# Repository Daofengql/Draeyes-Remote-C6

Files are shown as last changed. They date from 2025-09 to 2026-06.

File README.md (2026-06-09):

# Draeyes Remote C6 完整版遥控器

Draeyes Remote C6 是 Draeyes 兽装可动眼系列的完整版手持遥控器固件与硬件资料仓库。该版本面向 ESP32-C6 主控硬件，使用摇杆、肩键、同步拨动开关和可选 VEML7700 环境光传感器，通过纯 ESP-NOW 向接收端发送低延迟控制数据。

完整版遥控器适合正式使用场景：支持手动视线控制、全自动仿生眼动、自动眨眼、左右眼皮手动控制、摇杆锁定、摇杆零点校准、接收端配对，以及基于环境光的亮度或瞳孔响应控制。

早期设计中预留过 WiFi AP 和 MQTT 辅助功能，当前公开版本已经移除这些未使用模块，以减少固件体积、依赖库和运行时内存占用。

## 硬件配置

| 项目 | 说明 |
| --- | --- |
| 主控 | ESP32-C6 |
| 无线协议 | ESP-NOW |
| 主要输入 | 二轴模拟摇杆 |
| 按键 | R1、R2、LB、RB |
| 拨动开关 | BK，左右眼皮同步 |
| 光照传感器 | VEML7700，I2C |
| 参数保存 | EEPROM 模拟，用于保存摇杆零点和亮度补偿 |

### 引脚定义

| 信号 | GPIO |
| --- | --- |
| LB | 20 |
| RB | 18 |
| 摇杆 X | 5 |
| 摇杆 Y | 4 |
| 摇杆按键 | 21 |
| R1 | 23 |
| R2 | 22 |
| BK 同步开关 | 19 |
| I2C SDA | 0 |
| I2C SCL | 6 |

完整引脚定义见 `mapdata.h`。

## 目录结构

```text
.
├── Draeyes-Remote-C6.ino           # Arduino 主程序入口
├── RealisticEyeAnimation.h         # 自动眼动与自动眨眼算法
├── mapdata.h                       # 引脚、摇杆映射、EEPROM 校准逻辑
├── utils.h                         # ESP-NOW 初始化、光照映射等工具
├── hardware/
│   ├── pcb/                        # PCB 工程或导出文件
│   └── enclosure/                  # 外壳 STL 模型
├── .gitignore
├── LICENSE
└── README.md
```

为了兼容 Arduino IDE，`.ino` 文件保留在仓库根目录。

## Arduino 依赖

请在 Arduino IDE 或 PlatformIO 中安装：

| 库 | 用途 |
| --- | --- |
| ArduinoJson | 生成 ESP-NOW JSON 数据包 |
| Adafruit VEML7700 | 读取环境光传感器 |

同时需要安装支持 ESP32-C6 的 ESP32 Arduino Core。

## 编译与烧录

1. 用 Arduino IDE 打开 `Draeyes-Remote-C6.ino`。
2. 选择 ESP32-C6 对应开发板。
3. 安装上面列出的依赖库。
4. 使用 USB 连接遥控器。
5. 编译并上传固件。
6. 打开串口监视器，波特率设为 `115200`，查看启动、配对、校准和调光信息。

## 通信数据格式

控制器通过 ESP-NOW 发送 JSON 数据。

常规控制数据：

```json
{
  "req": "controller",
  "data": {
    "light": 1.0,
    "j1PotX": 127,
    "j1PotY": 127,
    "bkl": 1.0,
    "bkr": 1.0
  }
}
```

配对请求：

```json
{ "req": "pairing" }
```

眼皮样式切换请求：

```json
{ "req": "change" }
```

### 字段范围

| 字段 | 范围 | 含义 |
| --- | --- | --- |
| `j1PotX` | `0..255` | 眼球水平位置 |
| `j1PotY` | `0..255` | 眼球垂直位置 |
| `bkl` | `0.0..1.0` | 左眼皮开合度 |
| `bkr` | `0.0..1.0` | 右眼皮开合度 |
| `light` | `0.02..1.0` | 亮度或瞳孔光照控制值 |

## 按键布局

```text
          [ 摇杆 ]

      [ R1 ]       [ R2 ]

右侧边缘：
      [ LB ]  左眼皮 / 亮度增加
      [ BK ]  左右眼皮同步
      [ RB ]  右眼皮 / 亮度减少
```

## 常规操作

| 操作 | 功能 |
| --- | --- |
| 摇杆 | 控制眼球视线方向 |
| LB | 控制左眼皮闭合或眨眼 |
| RB | 控制右眼皮闭合或眨眼 |
| BK | 开启时右眼皮跟随左眼皮，实现双眼同步 |
| R1 连按 3 次 | 循环切换运动模式 |
| R2 连按 3 次 | 发送眼皮样式切换请求 |
| R2 长按 3 秒 | 锁定或解锁摇杆 |
| R1 + R2 长按 3 秒 | 发送接收端配对请求 |
| R1 + R2 + LB + RB 长按 3 秒 | 校准摇杆中心 |

## 运动模式

通过 R1 连按 3 次循环切换。

| 模式 | 视线控制 | 眼皮控制 |
| --- | --- | --- |
| 手动模式 | 摇杆控制 X/Y | LB/RB 手动控制左右眼皮 |
| 全自动模式 | 自动仿生眼动 | 自动眨眼 |
| 自动眨眼模式 | 摇杆控制 X/Y | 自动眨眼 |
| 锁定加自动眨眼模式 | 视线居中或锁定 | 自动眨眼 |

## 配对说明

1. 打开接收端设备。
2. 打开遥控器。
3. 同时按住 `R1 + R2` 约 3 秒。
4. 遥控器发送 `{ "req": "pairing" }`。
5. 接收端开始响应控制后即可松开按键。

当前固件使用 ESP-NOW 广播地址发送配对请求，接收端需要实现对应的配对处理逻辑。

## 摇杆校准

当松开摇杆后眼球仍然偏移时，需要执行摇杆零点校准。

1. 保证摇杆处于物理中心位置。
2. 同时按住 `R1 + R2 + LB + RB` 约 3 秒。
3. 串口输出 `Writing in EEPROM...` 和 `Done...` 后校准完成。
4. 松开所有按键。

校准后的摇杆中心值会保存到 EEPROM，下次开机继续生效。

## 摇杆锁定

在手动模式或自动眨眼模式下：

1. 长按 `R2` 约 3 秒。
2. 遥控器切换摇杆锁定状态。
3. 锁定后发送的 X/Y 为中心值。
4. 再次长按 `R2` 约 3 秒解除锁定。

## 环境光调光

VEML7700 光照传感器是可选硬件。固件启动时会自动检测传感器：

- 检测到传感器：启用调光配置模式。
- 未检测到传感器：禁用调光配置模式，并固定发送 `light = 1.0`。

### 进入与切换调光模式

长按 `R1` 约 3 秒，按下面顺序循环：

```text
主模式 -> 调光子模式 1 -> 调光子模式 2 -> 主模式
```

离开调光子模式时，亮度补偿参数会保存到 EEPROM。

### 调光子模式 1：跟随设置

| 操作 | 功能 |
| --- | --- |
| R2 单击 | 开启或关闭环境光跟随 |
| LB 单击 | 亮度补偿增加 `0.05` |
| RB 单击 | 亮度补偿减少 `0.05` |
| R1 长按 3 秒 | 保存并进入调光子模式 2 |

关闭环境光跟随后，遥控器发送 `light = 1.0`。

### 调光子模式 2：采样锁定

| 操作 | 功能 |
| --- | --- |
| R2 单击 | 采样当前环境光并锁定该亮度值 |
| LB 单击 | 亮度补偿增加 `0.05` |
| RB 单击 | 亮度补偿减少 `0.05` |
| R1 长按 3 秒 | 保存并退出到主模式 |

该模式适合现场灯光复杂、希望固定亮度或瞳孔响应的场景。

## 常见问题

### 长按 R1 不能进入调光模式

检查 VEML7700 的 SDA/SCL 接线，并重启遥控器。固件只有在启动时检测到传感器，才会启用调光模式。

### 摇杆回中后眼球仍偏移

执行 `R1 + R2 + LB + RB` 长按 3 秒的摇杆校准。

### 接收端没有响应

确认接收端已开机，并重新执行 `R1 + R2` 配对。还需要确认双方使用同一个 ESP-NOW 信道。

### 编译时出现 `wifi_tx_info_t` 相关错误

请升级 ESP32 Arduino Core。ESP32-C6 需要较新的 ESP-NOW 回调类型支持。

## 硬件资料

硬件资料放在 `hardware/` 目录：

```text
hardware/pcb/         PCB 工程或导出文件
hardware/enclosure/   外壳 STL 模型
```

打样前请自行核对主控封装、摇杆方向、按键方向、I2C 接线和外壳公差。

## 许可证

本项目使用 MIT License 开源，详见 `LICENSE`。

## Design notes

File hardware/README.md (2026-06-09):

# 硬件资料

这里存放 Draeyes Remote C6 完整版遥控器的硬件参考资料。

## 内容

```text
pcb/         PCB 工程或导出文件
enclosure/   外壳 STL 模型
```

## 打样前检查

- 核对 ESP32-C6 模块封装。
- 核对摇杆 X/Y 方向和中心值。
- 核对 R1、R2、LB、RB、BK 的按键方向。
- 核对 VEML7700 的 SDA/SCL 接线。
- 外壳 STL 需要根据打印机、材料、按键帽和装配方式微调公差。

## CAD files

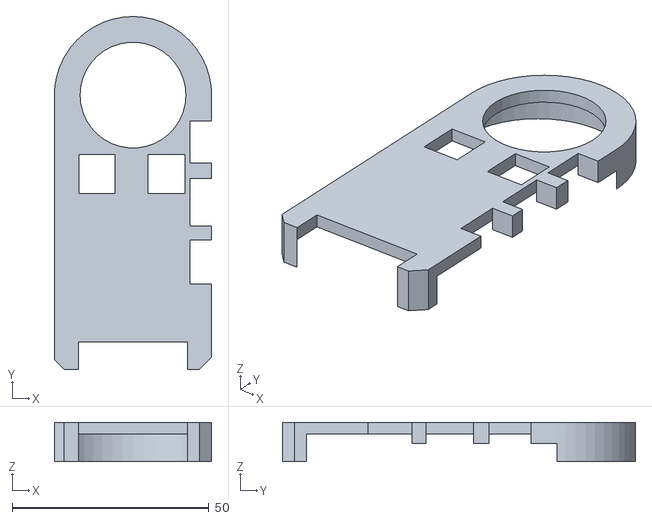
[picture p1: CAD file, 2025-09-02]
hardware/enclosure/0208002 - 零件3装配体4-1.STL
40.0 x 89.7 x 10.0

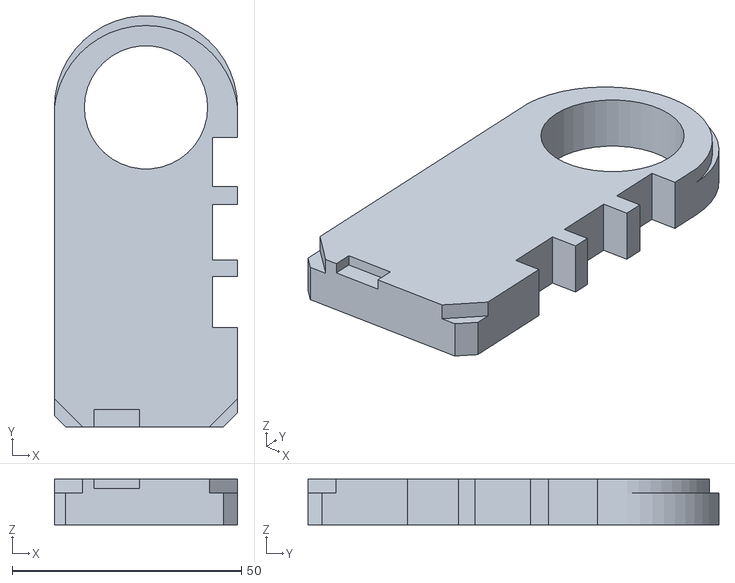
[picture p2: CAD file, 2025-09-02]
hardware/enclosure/0208002 - 零件2装配体4-1.STL
40.0 x 89.7 x 10.0

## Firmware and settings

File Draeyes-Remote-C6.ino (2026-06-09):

#include <WiFi.h>
#include <esp_now.h>
#include <ArduinoJson.h>
#include <Wire.h>              
#include "Adafruit_VEML7700.h" 
#include "utils.h"
#include "mapdata.h"
#include "RealisticEyeAnimation.h" 

#define KNEE_FACTOR 35.0
// EEPROM 中存放 Offset 的地址 (避开前 5 个字节)
#define EEPROM_ADDR_OFFSET 10 

// 定义数据包结构体
typedef struct Data_Package {
  byte j1PotX;
  byte j1PotY;
  bool j1Button;
  bool buttonLB;
  bool buttonRB;
  bool tSwitch1;
} Data_Package;
Data_Package data;

Adafruit_VEML7700 veml = Adafruit_VEML7700();

// 全局状态变量
EyeState eyeState; 

// 传感器与光照变量
volatile float currentLux = 0.0;
bool isSensorPresent = false; // 硬件检测标志位

// 调光模式与亮度控制变量
enum DimmingState {
  DIM_OFF,      // 主模式
  DIM_SUB1,     // 调光子模式1 (设置跟随)
  DIM_SUB2      // 调光子模式2 (采样锁定)
};
DimmingState dimmingState = DIM_OFF;

bool lightFollowMode = true;    
float manualLightValue = 1.0f;  
float finalLightToSend = 1.0f; 

// 亮度偏移量 (默认0.0)
float brightnessOffset = 0.0f; 

unsigned long previousMillis2 = 0;
const int SEND_INTERVAL = 10;
const int JSON_DOC_SIZE = 160;

// R1/R2 连续按下检测
static unsigned long lastPressTimeR1 = 0;
static int pressCountR1 = 0;
static unsigned long lastPressTimeR2 = 0;
static int pressCountR2 = 0;

// 长按检测变量
static unsigned long fourButtonPressStart = 0;
static bool fourButtonActionDone = false;
static unsigned long twoButtonPressStart = 0;
static bool twoButtonActionDone = false;

// 按键历史状态
bool lastStateR1 = HIGH; 
bool lastStateR2 = HIGH;
bool lastStateLB = HIGH;
bool lastStateRB = HIGH;

// 独立长按检测
static unsigned long r1LongPressStart = 0;
static bool r1LongPressDone = false;
static unsigned long r2LongPressStart = 0;
static bool r2LongPressDone = false;

// 眨眼特效变量
float bklValues[8];
int bklCount = 0; int bklIndex = 0; bool bklActive = false;
float currentBklValue = 1.0f;

float bkrValues[8];
int bkrCount = 0; int bkrIndex = 0; bool bkrActive = false;
float currentBkrValue = 1.0f;

// 控制模式
enum ControlMode {
  MANUAL_MODE, AUTO_FULL_MODE, AUTO_BLINK_MODE, AUTO_BLINK_LOCKED_MODE
};
ControlMode currentMode = MANUAL_MODE;
bool joystickLocked = false;

// --- 传感器任务 ---
void sensorTask(void *pvParameters) {
  for (;;) {
    // 只有当硬件存在时才读取
    if (isSensorPresent) {
        float rawLux = veml.readLux();
        currentLux = (currentLux * 0.8) + (rawLux * 0.2); 
    }
    vTaskDelay(110 / portTICK_PERIOD_MS); 
  }
}

// --- 辅助功能 ---
void saveOffsetToEEPROM() {
    EEPROM.put(EEPROM_ADDR_OFFSET, brightnessOffset);
    EEPROM.commit();
    Serial.println(" [EEPROM] Offset 已保存");
}

void performSpecialActionR1() {
  switch(currentMode) {
    case MANUAL_MODE: currentMode = AUTO_FULL_MODE; Serial.println("模式: 全自动"); break;
    case AUTO_FULL_MODE: currentMode = AUTO_BLINK_MODE; Serial.println("模式: 自动眨眼"); break;
    case AUTO_BLINK_MODE: currentMode = AUTO_BLINK_LOCKED_MODE; Serial.println("模式: 锁定+眨眼"); break;
    case AUTO_BLINK_LOCKED_MODE: currentMode = MANUAL_MODE; Serial.println("模式: 手动"); break;
  }
}

void performSpecialActionR2() {
  StaticJsonDocument<JSON_DOC_SIZE> doc;
  doc["req"] = "change";
  char jsonBuffer[25];
  size_t jsonLength = serializeJson(doc, jsonBuffer, sizeof(jsonBuffer));
  esp_now_send(peerMacAddress, (uint8_t *)jsonBuffer, jsonLength);
}

// --- R1 长按：切换调光模式 (带硬件检测与保存逻辑) ---
void performLongPressR1() {
  // 1. 如果没有传感器，禁止进入调光模式
  if (!isSensorPresent) {
      Serial.println(">>> 错误: 未检测到光照传感器，无法进入调光模式 <<<");
      return; 
  }

  // 2. 状态切换逻辑
  switch(dimmingState) {
    case DIM_OFF:
      dimmingState = DIM_SUB1;
      Serial.println(">>> 进入调光模式: 子模式1 [设置跟随] <<<");
      Serial.print("    当前 Offset: "); Serial.println(brightnessOffset);
      Serial.println("    操作: LB(+) / RB(-) 微调");
      break;
      
    case DIM_SUB1:
      // 切换前保存 Offset
      saveOffsetToEEPROM();
      dimmingState = DIM_SUB2;
      Serial.println(">>> 切换调光模式: 子模式2 [采样锁定] <<<");
      break;
      
    case DIM_SUB2:
      // 退出前保存 Offset
      saveOffsetToEEPROM();
      dimmingState = DIM_OFF;
      Serial.println("<<< 退出调光模式: 回到主控 <<<");
      break;
  }
}

// --- R2 长按：摇杆锁定 ---
void performLongPressR2() {
  if (dimmingState == DIM_OFF) {
      if(currentMode == MANUAL_MODE || currentMode == AUTO_BLINK_MODE) {
        joystickLocked = !joystickLocked;
        Serial.println(joystickLocked ? "R2长按: 摇杆锁定" : "R2长按: 摇杆解锁");
      }
  }
}

void resetData() {
  data.j1PotX = 127; data.j1PotY = 127;
  data.j1Button = 1; data.buttonLB = 1; data.buttonRB = 1; data.tSwitch1 = 1;
}

void setup() {
  Serial.begin(115200);
  delay(100);
  Wire.begin(I2C_SDA, I2C_SCL);
  
  pinmode_pullup();
  
  // 初始化 EEPROM
  eeprom_ini(); 
  resetData();

  // 【读取保存的 Offset】
  EEPROM.get(EEPROM_ADDR_OFFSET, brightnessOffset);
  // 如果读取到的是 NaN (首次使用)，重置为 0
  if (isnan(brightnessOffset)) {
      brightnessOffset = 0.0f;
  }
  Serial.print("加载 Offset: "); Serial.println(brightnessOffset);

  setupTasks();
  randomSeed(analogRead(0));
  init_eye_state(&eyeState);

  // --- 硬件检测逻辑 ---
  if (veml.begin()) {
    isSensorPresent = true;
    Serial.println("Sensor found (VEML7700)");
    
    veml.setGain(VEML7700_GAIN_1);
    veml.setIntegrationTime(VEML7700_IT_100MS); 

    // 只有存在传感器时才创建任务
    xTaskCreatePinnedToCore(sensorTask, "SensorTask", 4096, NULL, 1, NULL, 0);
  } else {
    isSensorPresent = false;
    Serial.println("!!! Sensor NOT found - Light control disabled !!!");
  }
}

void loop() {
    read_joydata();
    unsigned long now = millis();

    // 1. 计算亮度
    float mappedSensorValue = 1.0f; // 默认值
    if (isSensorPresent) {
        // 传入 brightnessOffset 进行计算
        mappedSensorValue = map_lux_fast_saturation(currentLux, KNEE_FACTOR, brightnessOffset);
    }

    // 2. 决定发送值
    if (!isSensorPresent) {
        finalLightToSend = 1.0f; // 无硬件强制为 1
    } else {
        if (lightFollowMode) {
            finalLightToSend = mappedSensorValue;
        } else {
            finalLightToSend = manualLightValue;
        }
    }

    // 读取按键
    bool currentStateR1 = digitalRead(R1);
    bool currentStateR2 = digitalRead(R2);
    bool currentStateLB = digitalRead(LB);
    bool currentStateRB = digitalRead(RB);
    bool currentStateTSwitch1 = digitalRead(BK);

    // ================= 通用层：长按检测 =================
    bool allFourPressed = (currentStateR1 == LOW && currentStateR2 == LOW && currentStateLB == LOW && currentStateRB == LOW);
    bool twoButtonPressed = (currentStateR1 == LOW && currentStateR2 == LOW && currentStateLB == HIGH && currentStateRB == HIGH);

    // R1 长按 (调光模式切换)
    if (!allFourPressed && !twoButtonPressed && currentStateR1 == LOW && currentStateR2 == HIGH) {
        if (r1LongPressStart == 0) { r1LongPressStart = now; r1LongPressDone = false; }
        else if (!r1LongPressDone && (now - r1LongPressStart >= 3000)) {
            performLongPressR1();
            r1LongPressDone = true;
        }
    } else { r1LongPressStart = 0; r1LongPressDone = false; }

    // R2 长按 (摇杆锁定)
    if (!allFourPressed && !twoButtonPressed && currentStateR2 == LOW && currentStateR1 == HIGH) {
        if (r2LongPressStart == 0) { r2LongPressStart = now; r2LongPressDone = false; }
        else if (!r2LongPressDone && (now - r2LongPressStart >= 3000)) {
            performLongPressR2();
            r2LongPressDone = true;
        }
    } else { r2LongPressStart = 0; r2LongPressDone = false; }


    // ================= 模式分流逻辑 =================
    if (dimmingState != DIM_OFF && isSensorPresent) {
        // >>>>>>>>>>>>>>>>> 调光模式 >>>>>>>>>>>>>>>>>
        
        bklActive = false; bkrActive = false; // 禁用眨眼特效

        // 【修改后】LB 检测：增加 Offset (变亮)
        if (lastStateLB == HIGH && currentStateLB == LOW) {
            brightnessOffset += 0.05f;
            if (brightnessOffset > 0.8f) brightnessOffset = 0.8f;
            Serial.print("Offset + : "); Serial.println(brightnessOffset);
        }

        // 【修改后】RB 检测：减少 Offset (变暗)
        if (lastStateRB == HIGH && currentStateRB == LOW) {
            brightnessOffset -= 0.05f;
            if (brightnessOffset < -0.8f) brightnessOffset = -0.8f;
            Serial.print("Offset - : "); Serial.println(brightnessOffset);
        }

        // R2 检测：功能键
        if (lastStateR2 == HIGH && currentStateR2 == LOW) {
            if (dimmingState == DIM_SUB1) {
                lightFollowMode = !lightFollowMode;
                if (!lightFollowMode) {
                    manualLightValue = 1.0f;
                    Serial.println("  [设置] 跟随已关闭 (Light = 1.0)");
                } else {
                    Serial.println("  [设置] 跟随已开启");
                }
            } 
            else if (dimmingState == DIM_SUB2) {
                manualLightValue = mappedSensorValue;
                lightFollowMode = false;
                Serial.print("  [采样] 锁定亮度: "); Serial.println(manualLightValue);
            }
        }

    } else {
        // >>>>>>>>>>>>>>>>> 主控模式 >>>>>>>>>>>>>>>>>
        
        // 1. 组合键
        if (allFourPressed) {
            if (fourButtonPressStart == 0) { fourButtonPressStart = now; fourButtonActionDone = false; }
            else if (!fourButtonActionDone && (now - fourButtonPressStart >= 3000)) { zero_test(); fourButtonActionDone = true; }
        } else { fourButtonPressStart = 0; fourButtonActionDone = false; }

        if (!allFourPressed && twoButtonPressed) {
            if (twoButtonPressStart == 0) { twoButtonPressStart = now; twoButtonActionDone = false; }
            else if (!twoButtonActionDone && (now - twoButtonPressStart >= 3000)) {
                StaticJsonDocument<JSON_DOC_SIZE> pairDoc; pairDoc["req"] = "pairing";
                char pairBuffer[256]; size_t pairLen = serializeJson(pairDoc, pairBuffer, sizeof(pairBuffer));
                esp_now_send(peerMacAddress, (uint8_t *)pairBuffer, pairLen); twoButtonActionDone = true;
            }
        } else if (!twoButtonPressed && !allFourPressed) { twoButtonPressStart = 0; twoButtonActionDone = false; }

        // 2. 三连击
        if (currentStateR1 == LOW && lastStateR1 == HIGH && currentStateR2 == HIGH) {
            if (now - lastPressTimeR1 <= 1000) pressCountR1++; else pressCountR1 = 1;
            lastPressTimeR1 = now;
            if (pressCountR1 >= 3) { performSpecialActionR1(); pressCountR1 = 0; }
        }
        if (currentStateR2 == LOW && lastStateR2 == HIGH && currentStateR1 == HIGH) {
            if (now - lastPressTimeR2 <= 1000) pressCountR2++; else pressCountR2 = 1;
            lastPressTimeR2 = now;
            if (pressCountR2 >= 3) { performSpecialActionR2(); pressCountR2 = 0; }
        }

        // 3. LB/RB 眨眼特效 (仅手动模式)
        if (currentMode == MANUAL_MODE) {
            if (currentStateLB != lastStateLB) {
                if (lastStateLB == HIGH && currentStateLB == LOW) { int count = random(6, 8); generateArray(1.0f, 0.0f, count, bklValues); bklCount = count; bklIndex = 0; bklActive = true; }
                else if (lastStateLB == LOW && currentStateLB == HIGH) { int count = random(7, 9); generateArray(0.0f, 1.0f, count, bklValues); bklCount = count; bklIndex = 0; bklActive = true; }
            }
            if (currentStateRB != lastStateRB) {
                if (lastStateRB == HIGH && currentStateRB == LOW) { int count = random(3, 5); generateArray(1.0f, 0.0f, count, bkrValues); bkrCount = count; bkrIndex = 0; bkrActive = true; }
                else if (lastStateRB == LOW && currentStateRB == HIGH) { int count = random(7, 9); generateArray(0.0f, 1.0f, count, bkrValues); bkrCount = count; bkrIndex = 0; bkrActive = true; }
            }
        }

        // 处理眨眼数组
        if (currentMode == MANUAL_MODE) {
            if (bklActive) { if (bklIndex < bklCount) currentBklValue = bklValues[bklIndex++]; else bklActive = false; }
            if (bkrActive) { if (bkrIndex < bkrCount) currentBkrValue = bkrValues[bkrIndex++]; else bkrActive = false; }
            if (currentStateTSwitch1 == HIGH) { currentBkrValue = currentBklValue; bkrActive = false; }
        }
    }

    // 更新按键状态
    lastStateR1 = currentStateR1; lastStateR2 = currentStateR2;
    lastStateLB = currentStateLB; lastStateRB = currentStateRB;

    // ================= 发送数据 =================
    if (now - previousMillis2 >= SEND_INTERVAL) {
        previousMillis2 = now;
        StaticJsonDocument<JSON_DOC_SIZE> doc;
        doc["req"] = "controller";
        JsonObject dataObj = doc.createNestedObject("data");
        
        dataObj["light"] = finalLightToSend; 

        switch(currentMode) {
            case MANUAL_MODE:
                if (dimmingState != DIM_OFF) { 
                     dataObj["j1PotX"] = 127; dataObj["j1PotY"] = 127;
                     dataObj["bkl"] = 1.0; dataObj["bkr"] = 1.0;
                } else {
                    if(joystickLocked) { dataObj["j1PotX"] = 127; dataObj["j1PotY"] = 127; }
                    else {
                        LX_to_send = map_normal(LX_read, 0, LX_zero, 255, LX_inverted);
                        LY_to_send = map_normal(LY_read, 0, LY_zero, 255, LY_inverted);
                        dataObj["j1PotX"] = constrain(LX_to_send, 0, 255);
                        dataObj["j1PotY"] = constrain(LY_to_send, 0, 255);
                    }
                    dataObj["bkl"] = currentBklValue; dataObj["bkr"] = currentBkrValue;
                }
                break;
                
            case AUTO_FULL_MODE:
                update_auto_movement(&eyeState, 3000); update_auto_blink(&eyeState); update_blink_state(&eyeState);
                {
                    int mx = map(eyeState.eyeCurrentX, 60, 180, 0, 255); int my = map(eyeState.eyeCurrentY, 60, 180, 0, 255);
                    dataObj["j1PotX"] = constrain(mx, 0, 255); dataObj["j1PotY"] = constrain(my, 0, 255);
                    dataObj["bkl"] = eyeState.eyeOpenness; dataObj["bkr"] = eyeState.eyeOpenness;
                }
                break;

            case AUTO_BLINK_MODE:
                update_auto_blink(&eyeState); update_blink_state(&eyeState);
                if(joystickLocked || dimmingState != DIM_OFF) { dataObj["j1PotX"] = 127; dataObj["j1PotY"] = 127; }
                else {
                    LX_to_send = map_normal(LX_read, 0, LX_zero, 255, LX_inverted);
                    LY_to_send = map_normal(LY_read, 0, LY_zero, 255, LY_inverted);
                    dataObj["j1PotX"] = constrain(LX_to_send, 0, 255);
                    dataObj["j1PotY"] = constrain(LY_to_send, 0, 255);
                }
                dataObj["bkl"] = eyeState.eyeOpenness; dataObj["bkr"] = eyeState.eyeOpenness;
                break;

            case AUTO_BLINK_LOCKED_MODE: 
                update_auto_blink(&eyeState); update_blink_state(&eyeState);
                dataObj["j1PotX"] = 127; dataObj["j1PotY"] = 127;
                dataObj["bkl"] = eyeState.eyeOpenness; dataObj["bkr"] = eyeState.eyeOpenness;
                break;
        }
        
        char jsonBuffer[256];
        size_t jsonLength = serializeJson(doc, jsonBuffer, sizeof(jsonBuffer));
        esp_now_send(peerMacAddress, (uint8_t *)jsonBuffer, jsonLength);
    }
}

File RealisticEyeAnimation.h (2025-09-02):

#ifndef REALISTIC_EYE_ANIMATION_H
#define REALISTIC_EYE_ANIMATION_H

#include <math.h>
#include <Arduino.h> // 引入Arduino核心库以使用PI常量

// --- 配置 ---
#define SCREEN_WIDTH 240
#define SCREEN_HEIGHT 240
#define MAP_RADIUS 120

// 眨眼状态枚举
typedef enum {
    NOT_BLINKING = 0,
    BLINK_CLOSING = 1,
    BLINK_OPENING = 2
} BlinkState;

// 眼睛状态结构体
typedef struct {
    // 【新增】用于存放每帧平滑移动的当前坐标
    float eyeCurrentX;
    float eyeCurrentY;

    // 用于定义移动起止点的坐标
    float eyeOldX, eyeOldY;
    float eyeNewX, eyeNewY;
    
    // 移动状态
    bool inMotion;
    uint32_t moveStartTimeMs;
    uint32_t moveDurationMs;
    uint32_t lastSaccadeStopMs;
    uint32_t saccadeIntervalMs;
    
    // 眨眼状态
    BlinkState blinkState;
    uint32_t blinkStartTimeMs;
    uint32_t blinkDurationMs;
    float blinkFactor;
    uint32_t timeOfLastBlinkMs;
    uint32_t timeToNextBlinkMs;
    
    // 眼睛开合度
    float eyeOpenness;
} EyeState;

// --- 辅助函数 ---
float random_float(float min, float max) {
    if (min >= max) return min;
    float scale = (float)rand() / (float)RAND_MAX;
    return min + scale * (max - min);
}

// --- 动画核心逻辑 ---

// 初始化眼睛状态
void init_eye_state(EyeState* state) {
    state->eyeOldX = state->eyeNewX = MAP_RADIUS;
    state->eyeOldY = state->eyeNewY = MAP_RADIUS;
    // 【修改】初始化新增的当前坐标
    state->eyeCurrentX = MAP_RADIUS;
    state->eyeCurrentY = MAP_RADIUS;
    
    state->inMotion = false;
    state->moveDurationMs = 0;
    state->moveStartTimeMs = millis();
    state->lastSaccadeStopMs = state->moveStartTimeMs;
    state->saccadeIntervalMs = random(500, 3001);
    
    state->blinkState = NOT_BLINKING;
    state->blinkStartTimeMs = 0;
    state->blinkDurationMs = 0;
    state->blinkFactor = 0.0f;
    state->timeOfLastBlinkMs = millis();
    state->timeToNextBlinkMs = random(2000, 6001);
    
    state->eyeOpenness = 1.0f;
}

// 触发一次眨眼
void trigger_blink(EyeState* state) {
    if (state->blinkState == NOT_BLINKING) {
        state->blinkState = BLINK_CLOSING;
        state->blinkStartTimeMs = millis();
        state->blinkDurationMs = random(50, 101);
    }
}

// 更新自动移动状态
void update_auto_movement(EyeState* state, uint32_t maxGazeMs) {
    uint32_t t = millis();
    uint32_t dt = t - state->moveStartTimeMs;

    if (state->inMotion) {
        // 如果移动时间已到
        if (dt >= state->moveDurationMs) {
            state->inMotion = false;
            // 更新起始点为上一次的目标点
            state->eyeOldX = state->eyeNewX;
            state->eyeOldY = state->eyeNewY;
            // 将当前坐标精确地对齐到目标点
            state->eyeCurrentX = state->eyeNewX;
            state->eyeCurrentY = state->eyeNewY;

            uint32_t limit = (maxGazeMs < 1000) ? maxGazeMs : 1000;
            state->moveDurationMs = random(35, limit + 1);
            
            if (!state->saccadeIntervalMs) {
                state->lastSaccadeStopMs = t;
                state->saccadeIntervalMs = random(state->moveDurationMs, maxGazeMs + 1);
            }
            state->moveStartTimeMs = t;

        } else {
            // 【新增】平滑插值计算
            // 计算移动进度 (0.0 to 1.0)
            float e = (float)dt / (float)state->moveDurationMs;
            // 使用缓动函数，使动作先加速后减速，更自然
            float e2 = e * e;
            e = e2 * (3.0f - 2.0f * e);
            
            // 根据进度计算当前帧的坐标
            state->eyeCurrentX = state->eyeOldX + (state->eyeNewX - state->eyeOldX) * e;
            state->eyeCurrentY = state->eyeOldY + (state->eyeNewY - state->eyeOldY) * e;
        }
    } else { // 如果眼睛当前是静止的
        if (dt > state->moveDurationMs) { // 停留时间结束，开始新的移动
            if ((t - state->lastSaccadeStopMs) > state->saccadeIntervalMs) {
                // 大眼跳 (Saccade) - 【修复坐标计算】
                // 使用固定的移动范围，确保坐标在合理区间内
                float maxRadius = 60.0f; // 固定最大移动半径
                float relativeX = random_float(-maxRadius, maxRadius);
                float maxY = sqrtf(maxRadius * maxRadius - relativeX * relativeX);
                float relativeY = random_float(-maxY, maxY);
                
                state->eyeNewX = MAP_RADIUS + relativeX;
                state->eyeNewY = MAP_RADIUS + relativeY;
                
                // 确保坐标在有效范围内（60-180，适配映射范围56-184）
                state->eyeNewX = constrain(state->eyeNewX, 60, 180);
                state->eyeNewY = constrain(state->eyeNewY, 60, 180);
                
                state->moveDurationMs = random(83, 167);
                state->saccadeIntervalMs = 0;
            } else {
                // 微眼跳 (Microsaccade) - 【修复坐标计算】
                float microRadius = 8.0f; // 固定微移动半径
                float dx = random_float(-microRadius, microRadius);
                float h = sqrtf(microRadius * microRadius - dx * dx);
                float dy = random_float(-h, h);
                
                state->eyeNewX = state->eyeOldX + dx;
                state->eyeNewY = state->eyeOldY + dy;
                
                // 确保坐标在有效范围内
                state->eyeNewX = constrain(state->eyeNewX, 60, 180);
                state->eyeNewY = constrain(state->eyeNewY, 60, 180);
                
                state->moveDurationMs = random(7, 26);
            }
            state->moveStartTimeMs = t;
            state->inMotion = true;
        }
    }
}

void update_auto_blink(EyeState* state) {
    uint32_t t = millis();
    if (t - state->timeOfLastBlinkMs >= state->timeToNextBlinkMs) {
        state->timeOfLastBlinkMs = t;
        trigger_blink(state);
        state->timeToNextBlinkMs = state->blinkDurationMs * 3 + random(2000, 6001);
    }
}

void update_blink_state(EyeState* state) {
    uint32_t t = millis();
    if (state->blinkState != NOT_BLINKING) {
        if (t - state->blinkStartTimeMs >= state->blinkDurationMs) {
            switch (state->blinkState) {
                case BLINK_CLOSING:
                    state->blinkState = BLINK_OPENING;
                    state->blinkDurationMs *= 2;
                    state->blinkStartTimeMs = t;
                    state->blinkFactor = 1.0f;
                    break;
                case BLINK_OPENING:
                    state->blinkState = NOT_BLINKING;
                    state->blinkFactor = 0.0f;
                    break;
            }
        } else {
            float progress = (float)(t - state->blinkStartTimeMs) / (float)state->blinkDurationMs;
            state->blinkFactor = (state->blinkState == BLINK_CLOSING) ? progress : 1.0f - progress;
        }
    }
    state->eyeOpenness = 1.0f - state->blinkFactor;
}

#endif // REALISTIC_EYE_ANIMATION_H

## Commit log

2025-09-02 添加外壳打印件
    [0208002 - 零件2装配体4-1.STL, 0208002 - 零件3装配体4-1.STL]
2025-09-02 添加PCB工程
2025-12-12 特性: 新增智能调光系统与非阻塞传感器任务
    1. 性能优化: 将 VEML7700 读取移至 Core 0 独立任务，解决主循环阻塞问题。
    2. 新增功能:
    - 引入调光状态机（跟随模式/锁定模式）。
    - 新增 LB/RB 亮度偏移微调功能，支持 EEPROM 断电保存。
    - 采用 Reinhard 色调映射算法优化光感曲线。
    - 增加硬件检测机制，无传感器时自动禁用调光功能。
    3. 按键重构:
    - R1 长按: 改为切换调光模式。
    - R2 长按: 改为摇杆锁定。
    4. 文档: 更新 README.md 至 v3.1.0。
    [mapdata.h]
2026-06-09 Open source controller docs and hardware files
    [0208002 - 零件2装配体4-1.STL, 0208002 - 零件3装配体4-1.STL]
